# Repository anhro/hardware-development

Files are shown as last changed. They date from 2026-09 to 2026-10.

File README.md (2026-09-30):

# Hardware Development: від схеми до прототипу



Навчальний репозиторій курсу: домашні завдання та наскрізний проєкт —
**контролер BLDC-двигуна** на STM32F405 (трифазний інвертор 12 В / 14 А).

**Поточний стан:** виконано ДЗ 1–8. Схема: силовий інвертор (AOD4184A),
драйвер затворів DRV8305, MCU STM32F405 з конфігурацією CubeMX; прошивка
збирається в CI. Друкована плата — не розпочата.
Відкриті інженерні питання — у [`design-notes.md`](motor-drive-controller/docs/design-notes.md).

| Що | Де |
|----|----|
| Звіти домашніх завдань і посилання на здачу (Release / PR) | [`assignments/`](assignments/) |
| Проєкт курсу: схема, прошивка, документація | [`motor-drive-controller/`](motor-drive-controller/) |
| Власні макетні проєкти (breadboard): схема, фото, прошивка | [`prototypes/`](prototypes/) |
| Як переглянути роботу (для викладача) | [`docs/reviewer-guide.md`](docs/reviewer-guide.md) |
| Процес роботи, інструменти, правила репозиторію | [`docs/workflow.md`](docs/workflow.md) |
| Релізи (звіт `.docx`, схема PDF, BOM для кожного ДЗ) | [Releases](https://github.com/anhro/hardware-development/releases) |

## Швидкий старт

```bash
git clone https://github.com/anhro/hardware-development.git
cd hardware-development
make setup          # git-налаштування + завантаження datasheets
make help           # усі команди
```

Основні команди:

| Команда | Результат |
|---|---|
| `make datasheets` | завантажує PDF за маніфестами `datasheets.txt` |
| `make hardware` | ERC, схема у PDF, BOM → `build/hardware/` |
| `make report HW=08` | звіт ДЗ 8 у `.docx` → `build/reports/` |
| `make firmware` | збірка прошивки (CMake + arm-none-eabi-gcc) |
| `make hardware PROJECT=stepper-motor` | те саме для іншого проєкту (корінь або `prototypes/`); так само `firmware` |

Потрібно: `git`, `make`, `python3`; для звітів — `pandoc` **або** Docker;
для схем — KiCad 10 **або** Docker; для прошивки — STM32CubeCLT або
`gcc-arm-none-eabi` + `cmake` + `ninja`. Для VS Code є рекомендовані розширення
(`.vscode/extensions.json`).

## Здача домашнього завдання

```
гілка hwNN → коміти → push → Pull Request (посилання на сайт курсу + .docx)
          → правки в тій самій гілці → Merge (merge commit) → тег hwNN → Release
```

CI перевіряє кожен PR (ERC, схема PDF, BOM, звіти `.docx`, прошивка) і за тегом
`hwNN` створює Release. Для кожного PR у папці завдання ведуться опис
(`pull-request.md`) і перевірка за чеклістом (`checklist.md`); шаблон чекліста —
[`.github/pull_request_template.md`](.github/pull_request_template.md).
Детально — [`docs/workflow.md`](docs/workflow.md).

## Структура

```
.
├── assignments/                 # ДЗ: README.md (звіт) + images/ + симуляції *.asc
│   └── homework_NN/             #   з ДЗ 8 — також pull-request.md, checklist.md
├── motor-drive-controller/
│   ├── docs/                    # архітектура, інженерні рішення
│   ├── hardware/
│   │   ├── kicad/               # проєкт KiCad: листи MCU, Gate Driver, Inverter
│   │   │   └── lib/parts/<PART>/ # символ, <PART>.pretty/ (footprint), 3D
│   │   ├── simulations/ltspice/ # симуляції вузлів
│   │   └── datasheets/          # лише маніфест datasheets.txt, PDF — локально
│   └── firmware/                # STM32CubeMX (.ioc) + CMake-проєкт + HAL
├── prototypes/                  # власні макетні проєкти, структура як у проєкті курсу
│   └── <name>/                  #   README.md (фото макета, таблиця з'єднань),
│                                #   docs/images/, hardware/{kicad,datasheets}/, firmware/
├── docs/                        # процеси та інструкції
├── tools/                       # скрипти автоматизації
├── .github/
│   ├── workflows/ci.yml         # CI: схема/BOM/прошивка всіх проєктів, звіти, релізи
│   └── pull_request_template.md # чекліст PR
└── Makefile
```

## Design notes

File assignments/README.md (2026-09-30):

# Домашні завдання

| № | Тема | Звіт | Файли проєкту | Здача |
|---|---|---|---|---|
| 1 | Робоче середовище, пошук компонента | [README](homework_01/README.md) | — | [hw01](https://github.com/anhro/hardware-development/releases/tag/hw01) |
| 2 | Основні поняття в електроніці | [README](homework_02/README.md) | LTspice: [`homework_02/`](homework_02/) | [hw02](https://github.com/anhro/hardware-development/releases/tag/hw02) |
| 3 | Компонентна база: пасивні та активні компоненти | [README](homework_03/README.md) | — | [hw03](https://github.com/anhro/hardware-development/releases/tag/hw03) |
| 4 | Аналогова схемотехніка. Симуляції схем | [README](homework_04/README.md) | LTspice: [`homework_04/`](homework_04/) | [hw04](https://github.com/anhro/hardware-development/releases/tag/hw04) |
| 5 | Цифрова схемотехніка. Симуляції схем | [README](homework_05/README.md) | LTspice, розрахунок ЦАП (`.xlsx`) | [hw05](https://github.com/anhro/hardware-development/releases/tag/hw05) |
| 6 | Інтерфейс KiCad та створення проєкту | [README](homework_06/README.md) | [`inverter.kicad_sch`](../motor-drive-controller/hardware/kicad/inverter.kicad_sch) | [hw06](https://github.com/anhro/hardware-development/releases/tag/hw06) |
| 7 | Архітектура MCU та системи живлення | [README](homework_07/README.md) | [`mcu.kicad_sch`](../motor-drive-controller/hardware/kicad/mcu.kicad_sch), [`.ioc`](../motor-drive-controller/firmware/motor-drive-controller.ioc) | [hw07](https://github.com/anhro/hardware-development/releases/tag/hw07) |
| 8 | Електричні двигуни. Принципи роботи і керування | [README](homework_08/README.md) | [`gate-driver.kicad_sch`](../motor-drive-controller/hardware/kicad/gate-driver.kicad_sch), [`mcu.kicad_sch`](../motor-drive-controller/hardware/kicad/mcu.kicad_sch), [`.ioc`](../motor-drive-controller/firmware/motor-drive-controller.ioc) | [PR #1](https://github.com/anhro/hardware-development/pull/1) |

**Здача:** Release `hwNN` — зафіксований стан на момент здачі з готовими файлами
(звіт `.docx`, схема PDF, BOM); PR — завдання на перевірці. Після прийняття PR
зливається в `master` і позначається тегом `hwNN` (див. [`docs/workflow.md`](../docs/workflow.md)).

ДЗ 1–7 перенесені з `.docx` (pandoc) без змін змісту. Починаючи з ДЗ 6 схеми
живуть у проєкті [`motor-drive-controller`](../motor-drive-controller/).
Починаючи з ДЗ 8 кожне завдання здається через Pull Request; у папці завдання,
крім звіту, лежать опис PR (`pull-request.md`) і перевірка за чеклістом
(`checklist.md`).

Новий звіт: `cp -r assignments/TEMPLATE assignments/homework_NN`,
`.docx` для сайту: `make report HW=NN`.

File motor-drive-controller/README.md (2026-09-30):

# motor-drive-controller

Контролер трифазного BLDC-двигуна: 12 В, до 14 А (168 Вт).

| Вузол | Стан | Файли |
|---|---|---|
| Силовий інвертор: 3 напівмости AOD4184A, шунти WSR5 7.5 мОм | схема (ДЗ 6) | [`hardware/kicad/inverter.kicad_sch`](hardware/kicad/inverter.kicad_sch) |
| MCU STM32F405RGT6: живлення, HSE 8 МГц, JTAG/SWD, VBAT, роз'єм датчиків Холла | схема (ДЗ 7, 8) | [`hardware/kicad/mcu.kicad_sch`](hardware/kicad/mcu.kicad_sch) |
| Драйвер затворів DRV83053PHP (DRV8305): накачка заряду, VREG 3.3 В, nFAULT/PWRGD | схема (ДЗ 8) | [`hardware/kicad/gate-driver.kicad_sch`](hardware/kicad/gate-driver.kicad_sch) |
| Конфігурація MCU: SYSCLK 168 МГц (HSE → PLL), TIM1 CH1–3/CH1N–3N → INHA…INLC, входи DRV_nFAULT/DRV_PWRGD, HALL1–3, ADC1 IN10 (NTC) | CubeMX (ДЗ 7, 8) | [`firmware/motor-drive-controller.ioc`](firmware/motor-drive-controller.ioc) |
| Прошивка: ініціалізація периферії, збірка CMake | збирається в CI | [`firmware/`](firmware/) |
| Друкована плата | не розпочато | [`hardware/kicad/motor-drive-controller.kicad_pcb`](hardware/kicad/motor-drive-controller.kicad_pcb) |

## Сигнали MCU

| Сигнал | Пін | Функція | Куди |
|---|-----|---|---|
| INHA / INLA | PA8 / PA7 | TIM1_CH1 / CH1N | DRV8305 |
| INHB / INLB | PA9 / PB0 | TIM1_CH2 / CH2N | DRV8305 |
| INHC / INLC | PA10 / PB1 | TIM1_CH3 / CH3N | DRV8305 |
| DRV_nFAULT | PC4 | вхід (open-drain, 10 кОм до 3.3 В) | DRV8305 |
| DRV_PWRGD | PC5 | вхід (open-drain, 10 кОм до 3.3 В) | DRV8305 |
| HALL1–HALL3 | PC6–PC8 | вхід, FT (5 V tolerant) | роз'єм J4 |
| TEMP_SENSE | PC0 | ADC1_IN10 | NTC на інверторі |

## Готовність до розведення плати

Схема ще не готова до PCB: 123 порушення ERC, не з'єднані мітки між листами,
не підключені WAKE/EN_GATE/SPI драйвера, footprint'и пасивних компонентів не
призначені. Повний перелік — у [`docs/design-notes.md`](docs/design-notes.md#відкриті-питання).

## Документація

- Архітектура: [`docs/architecture.md`](docs/architecture.md)
- Інженерні рішення та відкриті питання: [`docs/design-notes.md`](docs/design-notes.md)
- Прошивка: [`firmware/README.md`](firmware/README.md)

```bash
make hardware    # ERC + PDF схеми + BOM -> build/hardware/
make firmware    # збірка прошивки -> firmware/build/Debug/
```

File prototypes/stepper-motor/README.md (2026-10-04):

# stepper-motor

Макетний проєкт (breadboard): керування кроковим двигуном.

<!-- TODO: мета, двигун (тип, напруга, струм фази, кроків/оберт), драйвер, MCU -->
Кроковий двигун. Тип невідомий. Розмір 40 x 40 x 32 мм. Опір кожної з двох обмоток 24 Ом.
Підозрюю що при роботі з напругою 12 В він буде нормально працювати. Струм в такому випадку
буде дорівнювати I = V / R = 12 В / 24 Ом = 0.5 А - звичайний робочий струм для такого мотора.

Мета - навчитися працювати з кроковим двигуном та використовувати драйвер A4988.

| Вузол | Стан | Файли |
|---|---|---|
| Схема макета | не розпочато | [`hardware/kicad/`](hardware/kicad/) |
| Прошивка: ESP32 (Arduino), AccelStepper; кнопки вліво/вправо → 400 кроків | збирається | [`firmware/firmware.ino`](firmware/firmware.ino) |

## Макет

<!-- Фото: docs/images/breadboard.jpg (JPEG, стиснене, до ~500 КБ) -->
<!-- ![Макет](docs/images/breadboard.jpg) -->

## З'єднання

| Від | До | Сигнал | Примітка |
|-----|----|---|---|
| | | | |

## Прошивка

Скетч Arduino: [`firmware/firmware.ino`](firmware/firmware.ino). Плата, ядро ESP32 та
бібліотеки з точними версіями — у [`firmware/sketch.yaml`](firmware/sketch.yaml);
самі бібліотеки в git не зберігаються, `arduino-cli` завантажує їх під час збірки.

- **Arduino IDE 2:** File → Open → `firmware/firmware.ino`. Плата підставиться з
  `sketch.yaml`; бібліотеку AccelStepper встановити через Library Manager.
- **Командний рядок:** `make firmware PROJECT=stepper-motor` (потрібен `arduino-cli`
  у `PATH` або `ARDUINO_CLI=/шлях/до/arduino-cli`). Завантаження в плату:
  `arduino-cli upload -p /dev/ttyUSB0 --input-dir prototypes/stepper-motor/firmware/build prototypes/stepper-motor/firmware`.
- Нова бібліотека: `arduino-cli lib install <Name>`, потім додати рядок
  `- <Name> (<версія>)` у `libraries:` профілю в `sketch.yaml`.

## Команди

```bash
make hardware PROJECT=stepper-motor    # ERC + PDF схеми + BOM -> build/hardware/
make firmware PROJECT=stepper-motor    # збірка прошивки
make datasheets                        # PDF за hardware/datasheets/datasheets.txt
```

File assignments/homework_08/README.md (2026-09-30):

# Заняття 8: Електричні двигуни. Принципи роботи і керування.

## Опис завдання
Імпортувати компонент DRV8305 та створити схему його підключення відповідно до даташиту.

1\. Імпортуйте компонент **DRV8305**.

2\. Створіть схему підключення відповідно до даташиту. Даташит можна знайти
[в папці з додатковими ресурсами](https://drive.google.com/drive/folders/10yhwZ3x6XxErtohCtULcZ-SOZ1yHaNlk?usp=drive_link).

- Необхідні зовнішні конденсатори та резистори вказані в таблиці **External Components** (ст. 5).

- Припустіть, що драйвер живиться напругою **+3V3**.

- На вхід **VDRAIN** подайте напругу живлення двигуна **+12_M**.

3\. У проєкті **STM32CubeMX** визначте виходи advanced timer, налаштовані як **PWM Generation CH1..3 та CH1..3N**.
Позначте відповідні сигнали на схемі MCU та схемі DRV8305 (**INHA…INLC**).

4\. Додайте на схему сигнали **PWRGD** та **nFAULT**. У проєкті STM32CubeMX визначте їх як входи.

- Оскільки ці сигнали є **open-drain**, вони потребують підтягувальних резисторів.

- Рекомендовані номінали резисторів наведені в таблиці **Pin Functions** даташиту.

5\. Присвойте нетам локальні мітки (**labels**) для зручності роботи зі схемою.

6\. У даташиті на **STM32F7** (додаткові ресурси до заняття 7, файл **DM00037051.pdf**,
с. 48–61) визначте піни з підтримкою **FT (5 V tolerant I/O)** та підключіть до них
на схемі MCU датчики Холла **HALL1**, **HALL2**, **HALL3**.

## Рішення завдання

1\. Імпортуємо компонент **DRV8305**.

1\.1\. В пошуку на [сайті](https://www.snapeda.com/search/?q=DRV8305&search-type=parts)
я знайшов наступні компоненти Texas Instruments:

**45-V max 3-phase smart gate driver with current shunt amplifiers & SPI**:
- DRV83053PHPR
- DRV83053PHP
- DRV83055PHP
- DRV83055PHPR
- DRV8305NPHP
- DRV8305NPHPR

**Automotive 12-V battery 3-phase smart gate driver (grade 0 & grade 1)**:
- DRV83053QPHPRQ1
- DRV83055QPHPRQ1
- DRV8305NEPHPRQ1
- DRV83055QPHPQ1
- DRV8305NQPHPQ1
- DRV83053QPHPQ1
- DRV8305NEPHPQ1
- DRV8305NQPHPRQ1

**Automotive 3-Phase Motor Gate Driver Evaluation Module**:
- DRV8305-Q1EVM

**EVAL BOARD, DRV8305 DC MOTOR DRIVER**;
Application Sub Type:DC Brushless Motor;
Silicon Manufacturer:Texas Instruments;
Kit Application Type:Power Management - Motor Control;
Silicon Core Number:DRV8305;
Kit Contents:Eval Board DRV8305;
Product Range:-;
SVHC:No SVHC (27-Jun-2018);
Features:3-PH Brushless DC Motor Driver, 15A Continuous/20A Peak O/P Current,
Thermal Protection, 4.4V-45Vin:
- BOOSTXLDRV8305EVM

1\.2\. Вибір компонента:

- Крок 1: Нам потрібна мікросхема.

Все що закінчується на **EVM** нам не подходить - це компактна плата розширення.

- Крок 2: Автомобільний чи промисловий стандарт?

Все що із суфіксом -**Q1** або літерою **Q** - це автомобільний (Automotive) стандарт.
Вони сертифіковані за стандартом AEC-Q100 (Grade 0 або 1), витримують сильні вібрації
та екстремальні температури (від -40°C до +150°C) для роботи в реальних автомобілях
від 12-вольтового акумулятора. Скоріш за все вони більш дорогі і нам теж не підходять,
тому вибираємо без позначок **Q** та **Q1**. Нам потрібен звичайний промисловий стандарт.

- Крок 3: Яка напруга потрібна для живлення мікроконтролера?

Символ що вказаний на місці знака # **DRV8305#** означає живлення: **3** - драйвер має
вбудований стабілізатор на **3.3 В**, **5** - має стабілізатор на **5.0 В**, **N** -
стабілізатор вимкнено (обирається якщо на платі вже є потужне джерело живлення,
і від драйвера потрібні тільки функції керування мотором).

В нас вже є MCU що споживає 3.3 В живлення, тому нам підходить з цифрою **3**.

- Крок 4: Як плата буде збиратися на заводі (Пакування)?

Останні літери відповідають за форму випуску для виробництва. Корпус у всіх однаковий - **HTQFP-48** (**PHP**).
Але якщо без літери **R** (наприклад, **DRV83053PHP**), то це
означає що мікросхема постачається у пластикових лотках (**Trays**). Зручно для ручної
пайки або дрібних партій. З літорою **R** наприкінці (наприклад, **DRV83053PHPR**), то
постачається в рулонах / стрічці (**Tape & Reel**). Обирається для масового серійного
виробництва, де робот-розкладач автоматично бере чипи зі стрічки. Нам підходить без літери **R**.

- Крок 5: Мій вибір **DRV83053PHP**:

**Я обираю промислову версію DRV83053PHP, тому що мій пристрій не автомобільний,
мій мікроконтролер потребує живлення 3.3 В, а корпус PHP (HTQFP-48) зручний для розведення плати і ручної пайки.**

1\.2\. Скачую її символічне значення та місце для розташування:

Завантажую компонент з сайту [SnapEDA](https://www.snapeda.com/parts/DRV83053PHP/Texas%20Instruments/view-part/?ref=search&t=DRV8305&ab_test_case=b):

- Переміщую в папку parts:
`motor-drive-controller/hardware/kicad/lib/parts/DRV83053PHP/`:

```
motor-drive-controller/hardware/kicad/lib/parts/DRV83053PHP/
├── DRV83053PHP.kicad_sym
├── DRV83053PHP.step
└── DRV83053PHP.pretty/
    └── QFP50P900X900X120-49N.kicad_mod
```

В данному випадку я створюю додаткову теку DRV83053PHP.pretty - папку-бібліотеку посадкових місць
для драйвера DRV8305.

- Імпортую в KiCad → *Preferences → Manage Symbol/Footprint Libraries → Project Specific Libraries*:

2\. Створення схеми підключення відповідно до даташиту.

## Результат

1\. **Схема драйвера**.

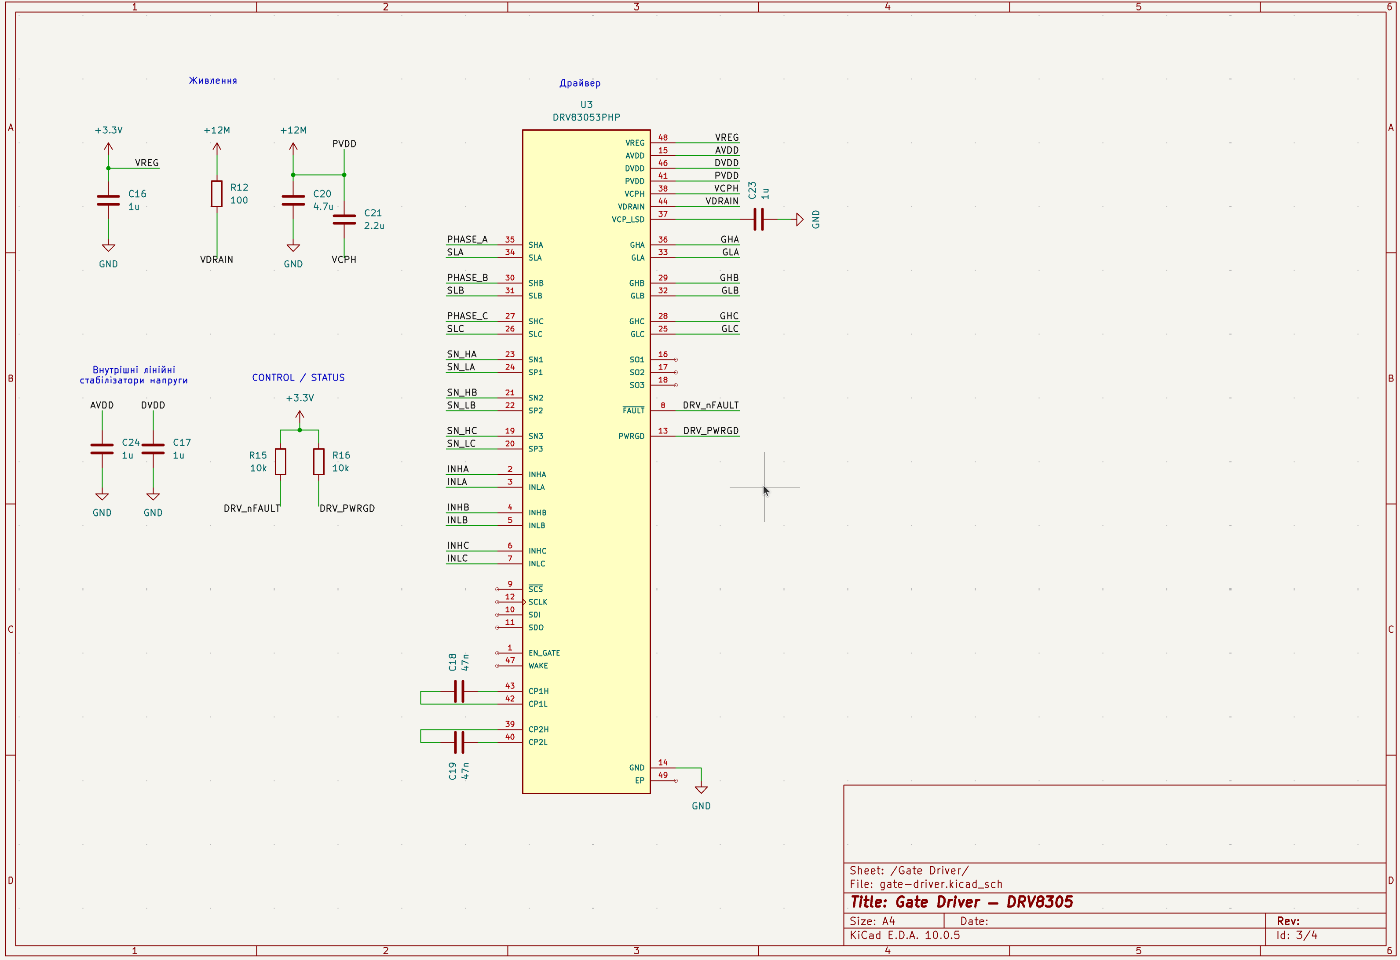
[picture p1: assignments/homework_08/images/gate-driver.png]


2\. **MCU з додатковими позначеннями виводів та роз'єм для датчиків Холла**.

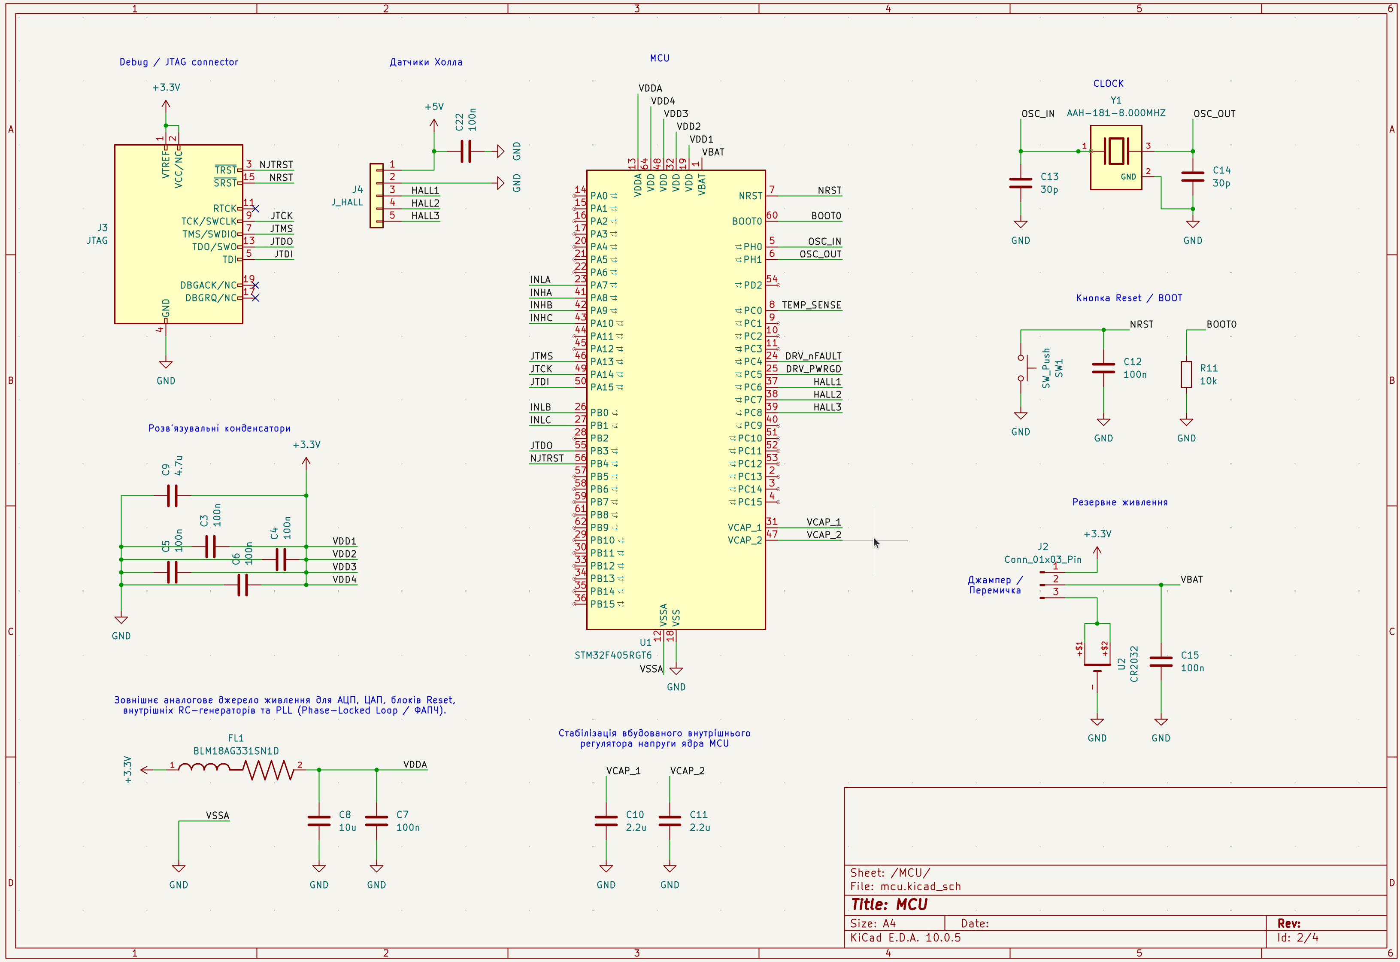
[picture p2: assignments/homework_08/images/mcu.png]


3\. **Розпіновка MCU**.

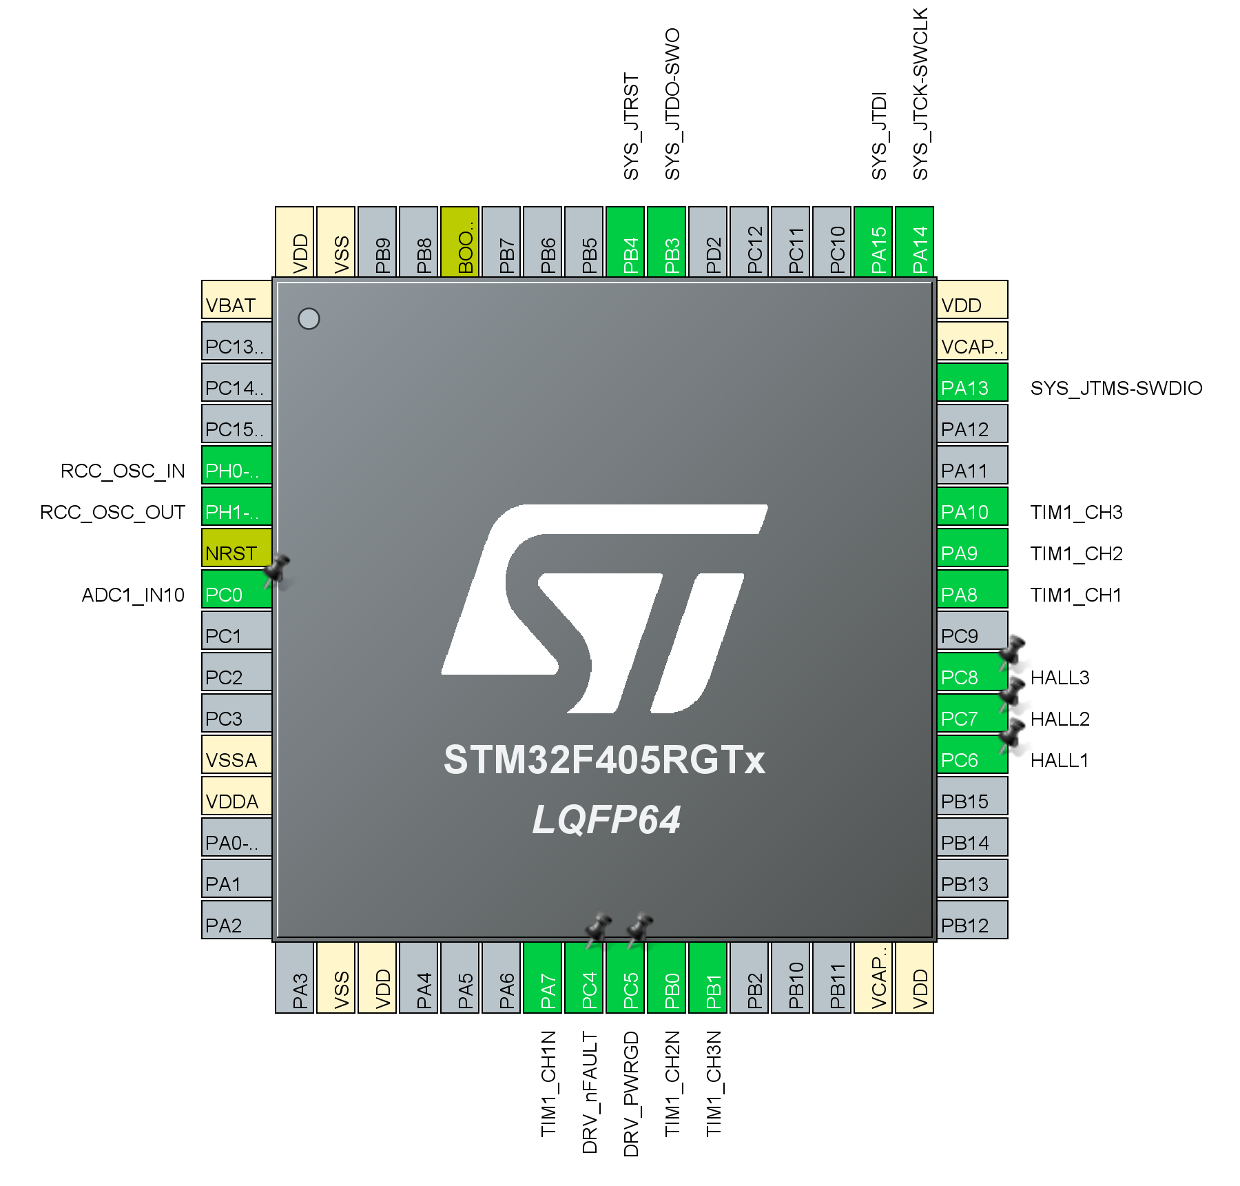
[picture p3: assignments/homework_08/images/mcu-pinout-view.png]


4\. **MCU піни з підтримкою FT**.

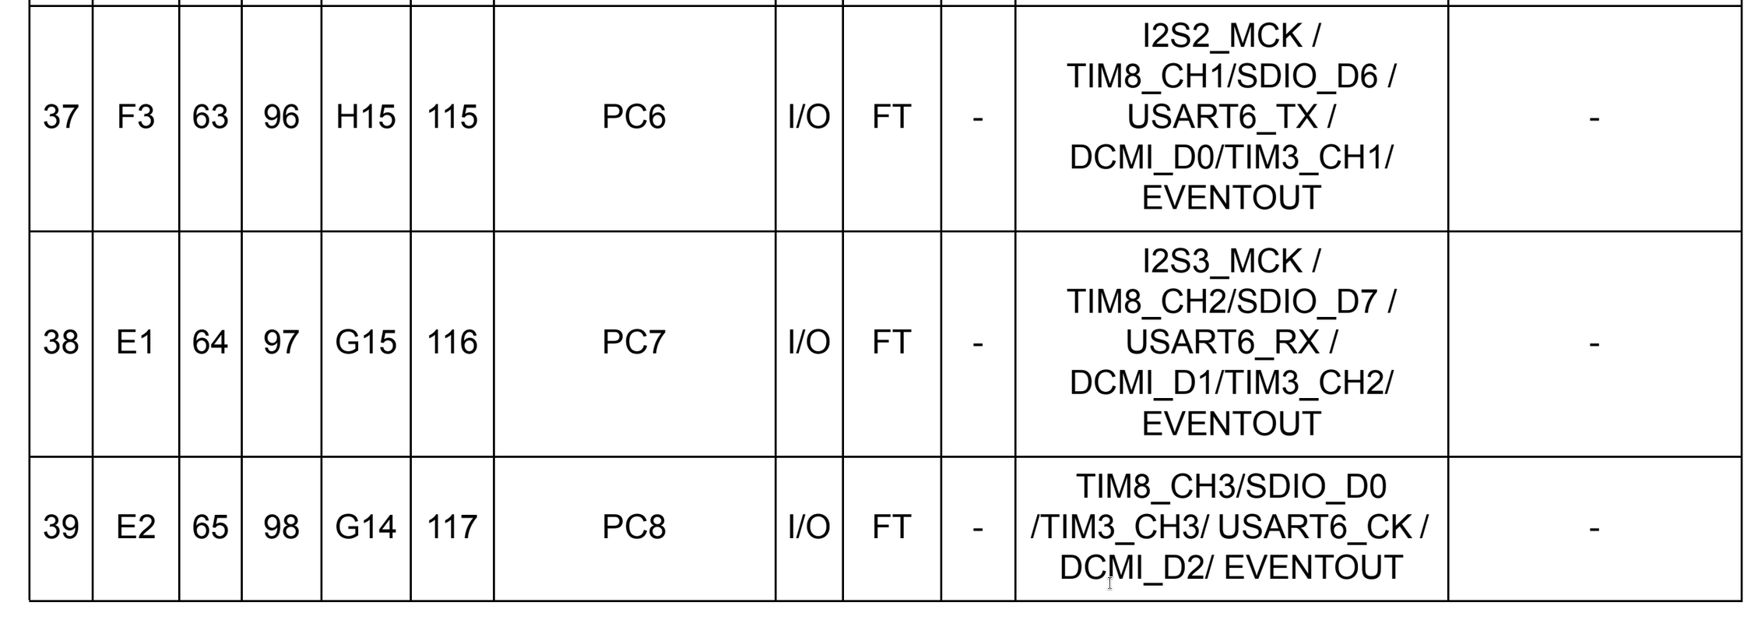
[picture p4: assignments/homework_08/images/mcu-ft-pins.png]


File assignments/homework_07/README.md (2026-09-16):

# Заняття 7: Архітектура MCU та системи живлення.

### Завдання 1

Опис завдання: в STM32CubeM сконфігурувати піни контролера STM32F405RGT (базовий варіант):

- TIM1 (CH1 CH1N)

- TIM1 (CH2 CH2N)

- TIM1 (CH3 CH3N)

- піни кварцового резонатора (RCC/HSE)

- входи програматора (SYS-JTAG)

- ADC (вхід для заміру показників термістора зі схеми 6 заняття)

Можна обрати інший мікроконтролер, якщо він має:

- за бажанням три ADC-периферії. Три окремих ADC забезпечить одночасний замір, а значить точніше керування на високих частотах обертання двигуна;

- advanced-control timer із можливістю формування комплементарного PWM для трьох каналів;

- підтримку dead time.

Вкажіть модель обраного мікроконтролера та прикріпіть скріншот Pinout view.

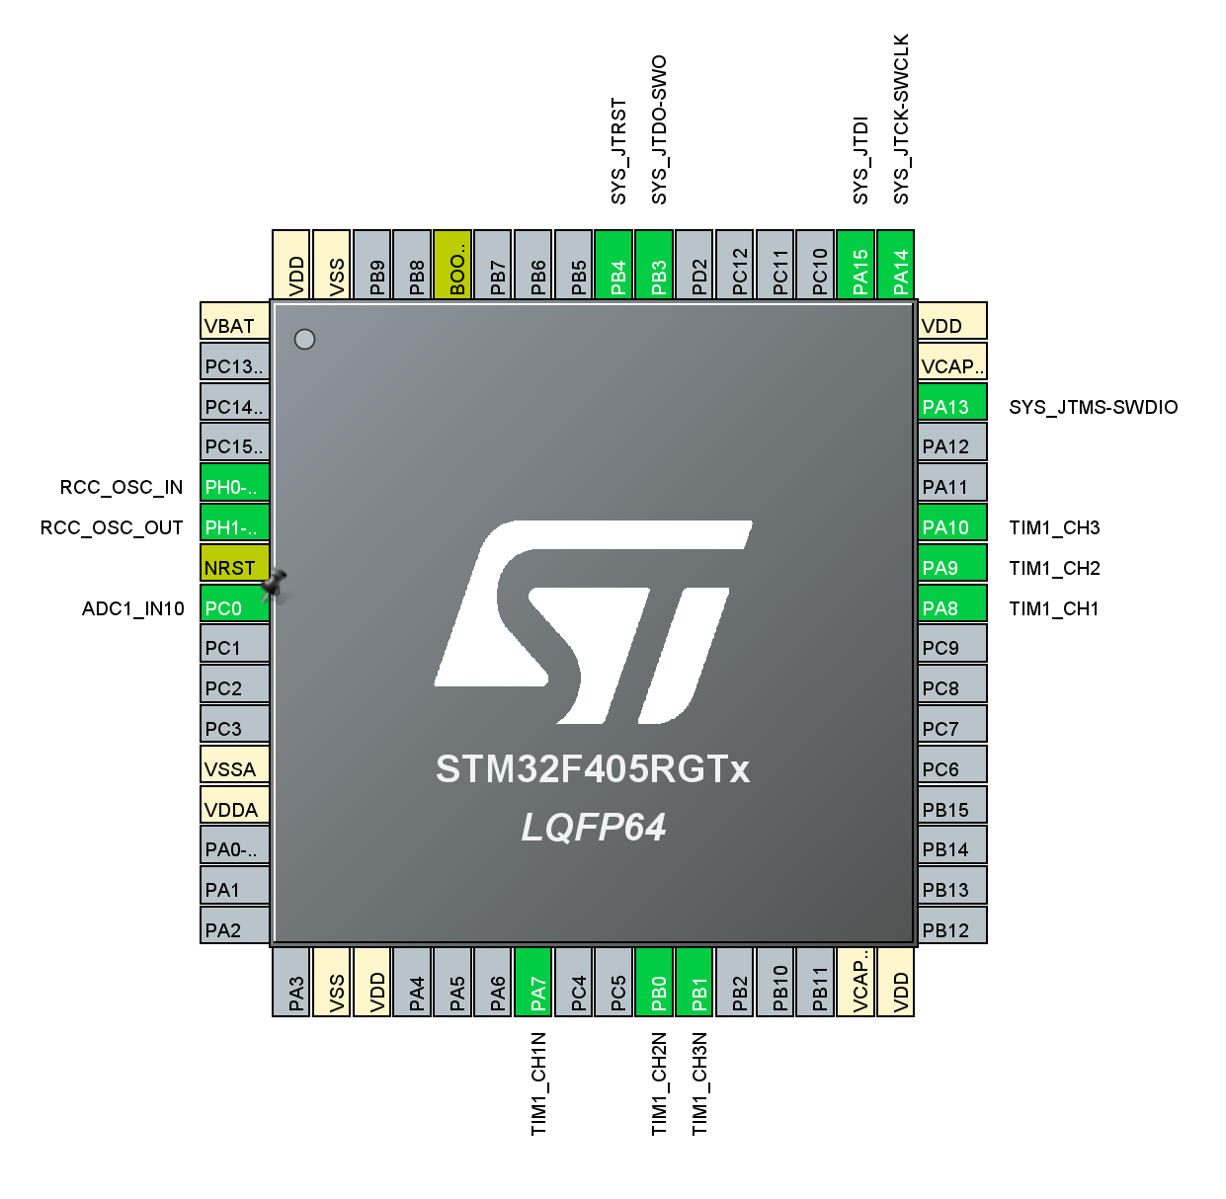
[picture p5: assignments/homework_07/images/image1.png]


### Завдання 2

Опис завдання: на окремому аркуші створіть схему мінімального підключення обраного мікроконтролера STM32Fxxx. Покажіть необхідні для роботи підключення відповідно до матеріалів слайдів 19–23: живлення та decoupling, VDDA/VSSA, NRST, BOOT, VBAT/backup domain, тактовий генератор тощо.

Вибираю кварц: AAH-181-8.000MHZ. Параметри з [datasheet](https://www.snapeda.com/parts/AAH-181-8.000MHZ/ABRACON/datasheet/) наступні:

Load capacitance (C<sub>L</sub>): 18.0 pF

C<sub>L</sub> = C1 x C2 / (C1 + C2) + Cs,

де Cs (Stray capacitance) - паразитна ємність плати Cs = 3 pF (2–5 pF)

Якщо C1 = C2 = Cext то:

C<sub>L</sub> = Cext / 2 + Cs --\> Cext / 2 = C<sub>L</sub> - Cs --\>

Cext = 2x(C<sub>L</sub> - Cs) = 2x(18.0 pF - 3 pF) = 30 pF

Додано ієрархічну структуру креслень де MCU — це поточна схема, Inverter — це схема силових ключів:

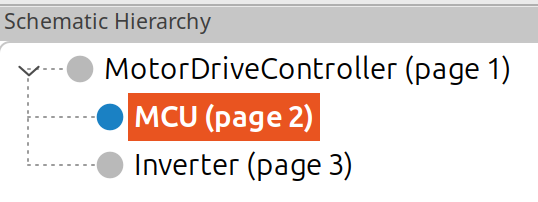
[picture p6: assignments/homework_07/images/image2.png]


Електрична схема підключення MCU STM32F405RGT6:

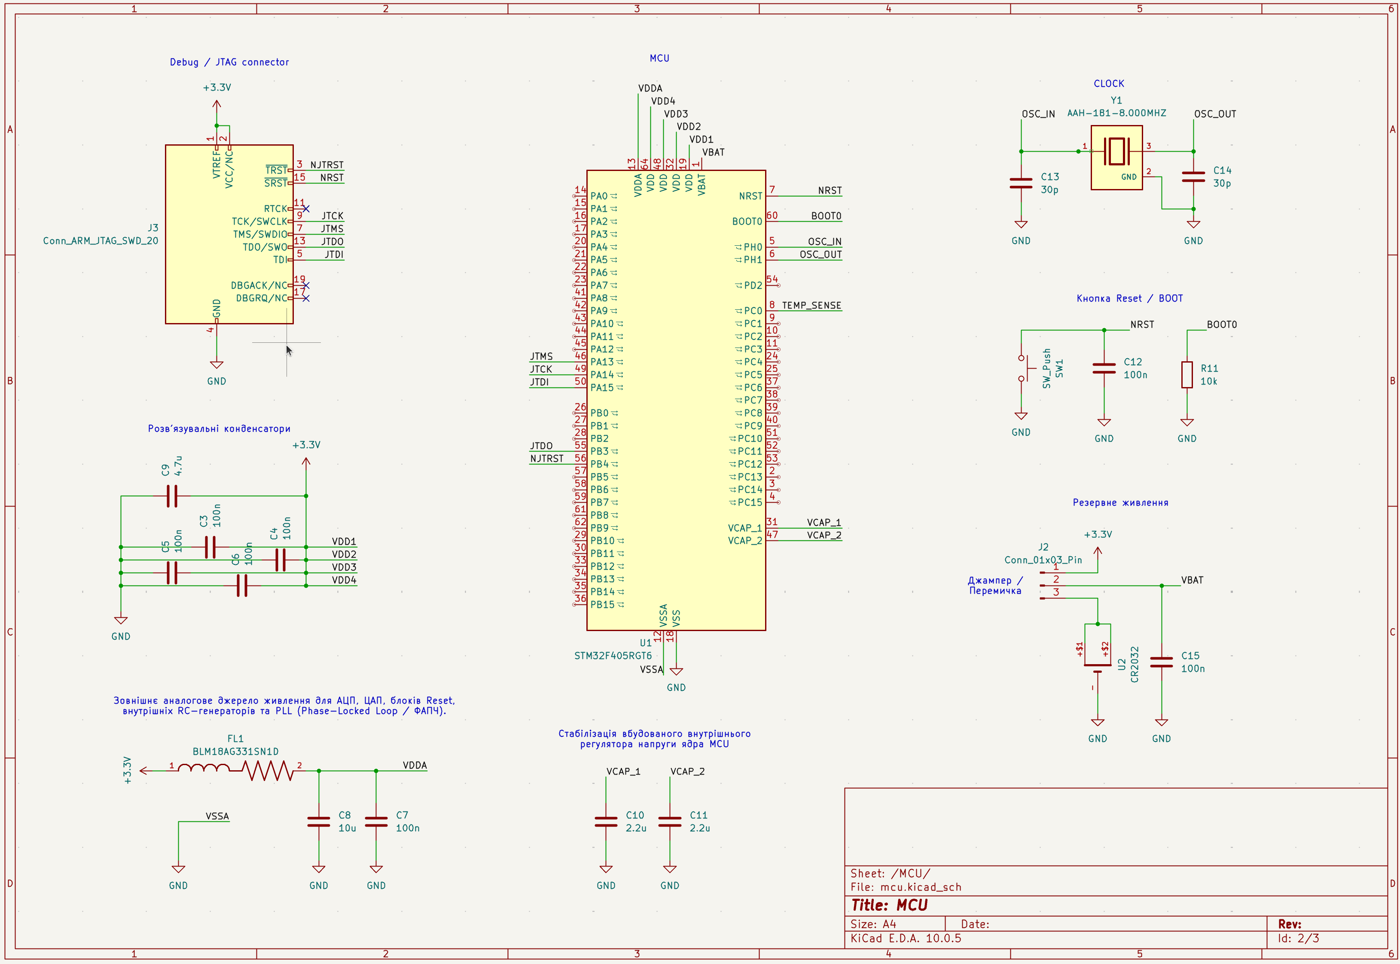
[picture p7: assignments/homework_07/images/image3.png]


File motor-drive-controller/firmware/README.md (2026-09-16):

# Прошивка

Джерело правди для пінів, тактування та периферії —
[`motor-drive-controller.ioc`](motor-drive-controller.ioc) (STM32CubeMX).
Код пишеться лише між маркерами `/* USER CODE BEGIN … */ … /* USER CODE END … */`
або в окремих файлах — інакше CubeMX перезапише його при генерації.

## Що в git

| Шлях | У git | Чому |
|---|:-----:|---|
| `motor-drive-controller.ioc` | ✅ | конфігурація |
| `Core/`, власні модулі | ✅ | код |
| `CMakeLists.txt`, `CMakePresets.json`, `cmake/`, `*.ld`, `startup_*.s` | ✅ | збірка без CubeMX (CI) |
| `Drivers/` (лише необхідні файли HAL/CMSIS) | ✅ | фіксована версія бібліотек → відтворювана збірка; змінюється тільки при оновленні FW-пакета |
| `build/`, `EWARM/`, `.mxproject` | ❌ | генерується / не використовується |

## Перехід на CMake + VS Code (одноразово)

У `.ioc` вже виставлено: *Toolchain/IDE* = **CMake**, *Code generator* =
**Copy only the necessary library files**, ім'я проєкту `motor-drive-controller`.
Раніше проєкт був згенерований для IAR EWARM і з повною копією CMSIS (57 МБ).

```bash
cd motor-drive-controller/firmware
rm -rf Drivers EWARM .mxproject     # усе це відтворюється з .ioc і FW_F4 V1.28.3
```

1. Відкрити `.ioc` у STM32CubeMX → перевірити *Project Manager* → **Generate Code**.
2. Виправити тактування й dead-time (див. [design-notes](../docs/design-notes.md#відкриті-питання)).
3. VS Code з розширенням **STM32Cube for Visual Studio Code** → *Import CMake project*.
4. Перевірити збірку: `make firmware` (з кореня репозиторію).

Для цього потрібен STM32CubeCLT (компілятор, CMake, Ninja, ST-LINK GDB server) —
розширення VS Code запропонує встановити його автоматично.

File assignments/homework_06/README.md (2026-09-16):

# Заняття 6: Інтерфейс KiCad та створення проєкту.

### Завдання 1 — підбір силових ключів та шунтів

Є приклад трифазної мостової схеми керування (три напівмости) двигуном ([у папці з додатковими ресурсами](https://drive.google.com/drive/folders/1CCpVQM1FImKKAaBql2j669Kx7Z-wt8mC?usp=sharing)). Потужність двигуна з навантаженням при напрузі 12В: 168Вт (~14А).

**Розрахувати:**

- Підібрати силові ключі для трьох напівмостів керування двигуном:

- запас по струму — мінімум 1.5–2 рази від розрахункового значення, з урахуванням температурних змін (дератинг Id при робочій температурі кристала/корпуса);

- запас по напрузі — мінімум 1.5–2 рази, комфортний запас — x3.

- Підібрати шунти для виміру струму в обмотках (коефіцієнт підсилення підсилювача — 20 В/В):

- номінал шунта розрахувати з запасом на 50% понад очікуваний піковий струм;

- 3.3В — максимальна напруга вимірювального сигналу на виході підсилювача

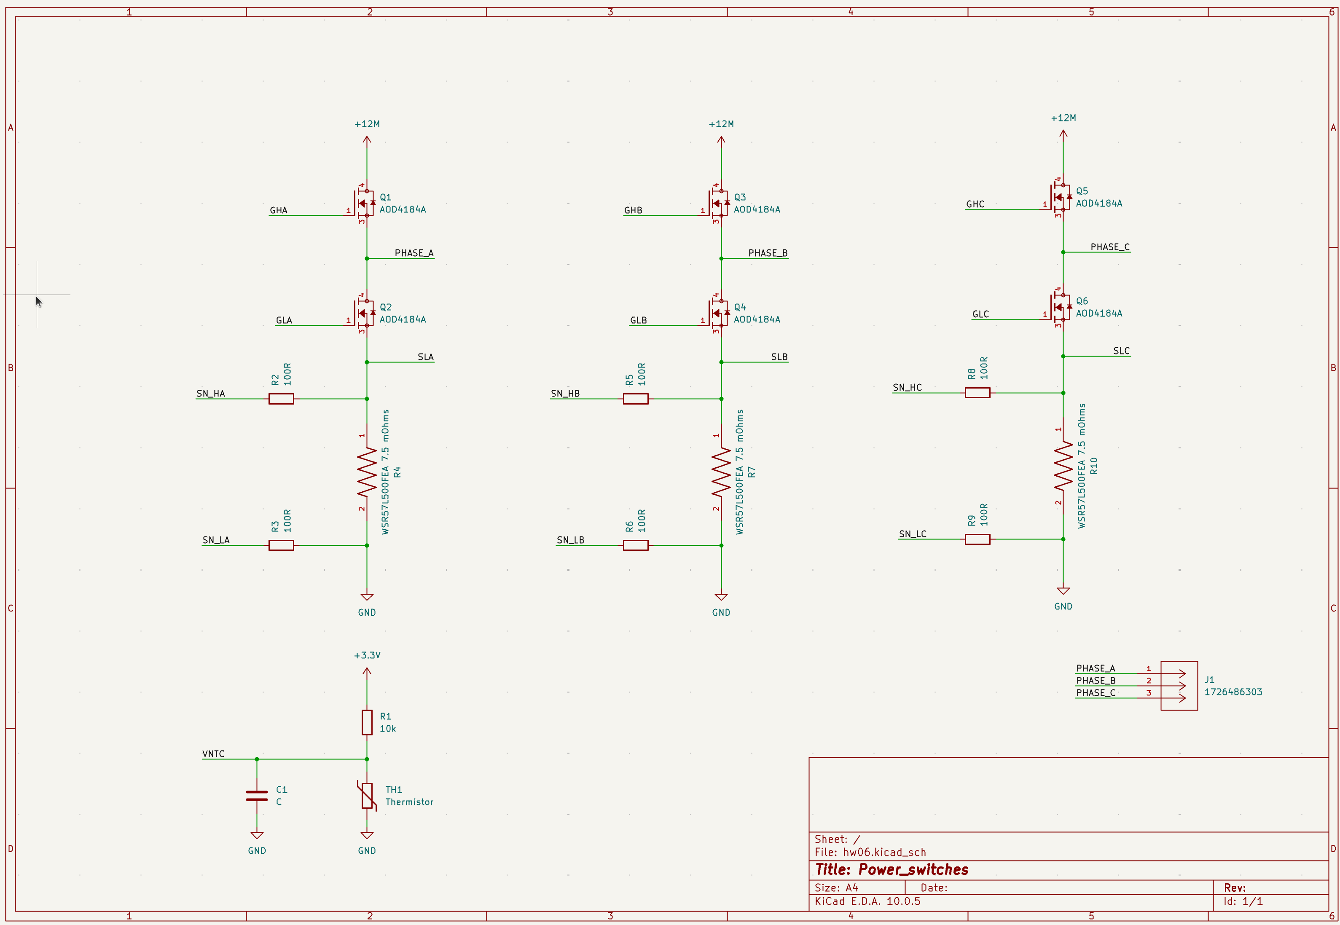
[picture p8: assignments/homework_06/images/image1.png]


**Підібрати ключі:**

Виявляється (для мене :) що одночасно струм через трифазний двигун, що керується ключами MOSFET, поступає тільки через одну пару фаз — AB, BC, CA (на відміну від трьохфазного двигуна змінного струму AC), і струм проходить максимальний для постійного джерела живлення — Imax = 168 Вт / 12 А = 14 А.

Добре. Тоді закладемо запас, що вказаний в умовах задачі - запас по струму — мінімум 1.5–2 рази від розрахункового значення.

Для запасу в 1.5 рази відповідний струм буде Imax 1.5 = 14 А \* 1.5 = 21 А.

Для запасу в 2 рази відповідний струм буде Imax 2 = 14 А \* 2 = 28 А.

Закладемо запас по напрузі - запас по напрузі — мінімум 1.5–2 рази, комфортний запас — x3.

Для запасу в 1.5 рази Umax = 12 В \* 1.5 = 18 В.

Для запасу в 2 рази Umax = 12 В \* 2 = 24 В.

Для комфортного запасу в 3 рази Umax = 12 В \* 3 = 36 В.

В нашому випадку для підбору ключів нам потрібен ключ у якого максимальні значення більші або дорівнюють розрахованим величинам:

Imax = {21, 28} А, Umax = {18, 24, 36} В.

N-Channel [MOSFETs](https://octopart.com/search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)

| MOSFET | V<sub>DS</sub> | I<sub>D</sub> A |  | R<sub>DS(on)</sub> | Q<sub>g</sub> | V<sub>GS</sub> | Корпус | Примітка |
|----|:--:|:--:|:--:|:--:|:--:|:--:|:--:|:--:|
|  |  | 25 °C | 100 °C |  |  |  |  |  |
| [IRLR3714](https://octopart.com/datasheet/infineon/IRLR3714) | 20 | 36 | 31 (70 °C) | 0.02 | 6.5 | 10 V | D-Pak / I-Pak |  |
| [IRFR3704](https://octopart.com/datasheet/infineon/IRFR3704) | 20 | 75 | 63 (70 °C) | 0.0095 | 19 | 10 V | D-Pak / I-Pak |  |
| [IPD060N03LGATMA1](https://octopart.com/datasheet/infineon/IPD060N03LGATMA1) | 30 | 50 | 50 | 0.006 | 10.8 | 10 V | PG-TO251-3 |  |
| [FQP30N06L](https://octopart.com/datasheet/onsemi/FQP30N06L) | 60 | 32 | 22.6 | 0.035 | 15 | 10 V | TO-220 |  |
| [IRFZ34NPBF](https://octopart.com/datasheet/infineon/IRFZ34NPBF) | 55 | 29 | 20 | 0.040 | 34 | 10 V | TO-220AB |  |
| [STD30NF04LT](https://octopart.com/datasheet/stmicroelectronics/STD30NF04LT) | 40 | 30 | 21 | 0.03 | 17 | 10 V | DPAK |  |
| [IRL3705NPBF](https://octopart.com/datasheet/infineon/IRL3705NPBF) | 55 | 89 | 63 | 0.010 | 98 | 10 V | TO-220AB |  |
| [IRLR2703](https://octopart.com/datasheet/international-rectifier/IRLR2703) | 30 | 23 | 16 | 0.045 | 15 | 10 V | D-Pak / I-Pak |  |
| [IPD050N03L](https://octopart.com/datasheet/infineon/IPD050N03LGATMA1) | 30 | 50 | 50 | 0.005 | 15 | 10 V | PG-TO252-3-11 |  |
| [SUD50N03-06AP-E3](https://octopart.com/datasheet/vishay/SUD50N03-06AP-E3) | 30 | 30 | 25 (70 °C) | 0.0046 | 30 | 10 V | TO-252 |  |
| [AOD4184A](https://octopart.com/datasheet/alpha-omega-semiconductor/AOD4184A) | 40 | 50 | 40 | 0.0058 | 27 | 10 V | TO-252 |  |
| [IRFR3303PBF](https://octopart.com/datasheet/infineon/IRFR3303PBF) | 30 | 33 | 21 | 0.031 | 29 | 10 V | D-Pak / I-Pak |  |
| [IPD06N03LAG](https://octopart.com/datasheet/infineon/IPD06N03LAG) | 25 | 50 | 50 | 0.0057 | 17 | 10 V | P-TO252-3-11 |  |
| [STP60NF06](https://octopart.com/datasheet/stmicroelectronics/STP60NF06) | 60 | 60 | 42 | 0.014 | 54 | 10 V | TO-220 |  |
| [IRLZ44NPBF](https://octopart.com/datasheet/infineon/IRLZ44NPBF) | 55 | 47 | 33 | 0.022 | RV | 10 V | TO-220AB |  |

Таблиця кандидатів у відбір кращих силових ключів

<table>
<colgroup>
<col style="width: 15%" />
<col style="width: 28%" />
<col style="width: 26%" />
<col style="width: 28%" />
</colgroup>
<thead>
<tr>
<th style="text-align: center;">I<sub>D</sub> \ V<sub>DS</sub></th>
<th style="text-align: center;">≥18 V</th>
<th style="text-align: center;">≥24 V</th>
<th style="text-align: center;">≥36 V</th>
</tr>
</thead>
<tbody>
<tr>
<td style="text-align: center;"><strong>≥21 A</strong></td>
<td style="text-align: center;">---</td>
<td>1. IRLR2703 (30V, 23A)</td>
<td style="text-align: center;">---</td>
</tr>
<tr>
<td style="text-align: center;"><strong>≥28 A</strong></td>
<td style="text-align: center;"><p>1. IRLR3714 (20V, 36A)</p>
<p>2. IRFR3704 (20V, 75A)</p></td>
<td><p>1. IPD060N03L (30V, 50A)</p>
<p>2. IPD050N03L (30V, 50A)</p>
<p>3. SUD50N03 (30V, 30A)</p>
<p>4. IRFR3303PBF (30V, 33A)</p>
<p>5. IPD06N03LAG (25V, 50A)</p></td>
<td style="text-align: center;"><p>1. FQP30N06L (60V, 32A)</p>
<p>2. IRFZ34NPBF (55V, 29A)</p>
<p>3. STD30NF04LT (40V, 30A)</p>
<p>4. IRL3705NPBF (55V, 89A)</p>
<p>5. AOD4184A (40V, 50A)</p>
<p>6. STP60NF06 (60V, 60A)</p>
<p>7. IRLZ44NPBF (55V, 47A)</p></td>
</tr>
</tbody>
</table>

Вибираємо по максимальній напрузі та струму (≥28 A та ≥36 V) — права нижня комірка:

Найкращим вибором є AOD4184A (R<sub>DS</sub>(on) = 0.0058 Ом) або IRL3705NPBF (має великий запас за струмом 89A та низький опір 0.010 Ом).

**Мій вибір:**

З двох кандидатів вибираю AOD4184A. Безперервний струм стоку при 25 °C I<sub>D</sub> = 50A. Крім того він гарно тримається при нагріванні до 100 °C (I<sub>D</sub> = 40A).

Це також ключ з низьким опором відкритого каналу R<sub>DS</sub>(on) = 0.0058 Ом. Чим менше опору, тим менше втрат потужності на нагрівання.

Формула для розрахунку втрати потужності: P = I<sup>2</sup> x R<sub>DS</sub>(on).

Подивимося на різницю в нагріванні при струмі двигуна, наприклад, 25 А.

Наприклад,

- Для IRL3705NPBF: R<sub>DS</sub>(on) = 0.010 Ом. --\> P = 25<sup>2</sup> x 0.010 = 6.25 Вт

- Для AOD4184A: R<sub>DS</sub>(on) = 0.0058 Ом. --\> P = 25<sup>2</sup> x 0.0058 = 3.625 Вт

Тобто при одному і тому ж струмі на ключі AOD4184A виділяється майже в 2 рази менше ніж на IRL3705NPBF.

Крім того це транзистор в SMD-корпусі (TO-252).

Згідно datasheet, у нього вказаний параметр Power Dissipation A (це використання в реальних умовах без радіатора — на платі достатньо наявності квадратної площадки в 1 квадратний дюйм 25.4 x 25.4 мм = 6.45 см<sup>2</sup>):

- При T<sub>A</sub> = 25 °C --\> P<sub>DSM</sub> = 2.3 Вт.

- При T<sub>A</sub> = 100 °C --\> P<sub>DSM</sub> = 1.5 Вт.

При струмі в 14 А розраховуємо потужність розсіювання, Вт:

- P = 14<sup>2</sup> x 0.0058 = 1.1368 Вт ≈ 1.15 Вт.

**Висновок:**

Ключ AOD4184A у SMD корпусі при наявності на платі мідної площадки площою в 6.45 см<sup>2</sup>, навіть при нагріві навколишнього середовища до температури 100 °C цей ключ зможе розсіювати потужність в 1.15 Вт (1.15 Вт \< 1.5 Вт) без будь-яких зовнішніх алюмінієвих радіаторів з запасом майже в 1.5 рази. Тоді як при кімнатній температурі цей показник виявляється ще більше комфортним (1.15 Вт \< 2.3 Вт) — в 2 рази менший.

**Порахуємо шунти:**

Нам відомі наступні первинні умови:

- Коефіцієнт підсилення підсилювача A<sub>CL</sub> = 20 В/В;

- Номінал шунта розрахувати з запасом на 50% (SF = 1.5) понад очікуваний піковий струм;

- Максимальна напруга вимірювального сигналу на виході підсилювача:

  Uout max = 3.3 В;

Підемо з кінця — найбільше наше обмеження — це максимальна напруга на виході підсилювача, яку нам не можна перевищувати.

Розраховуємо максимальну напругу на вході підсилювача:

Uin max = Uout max / A<sub>CL</sub> = 3.3 В / 20 = 0.165 В.

І відповідно максимальна напруга на шунті повинна дорівнювати максимальній вхідній напрузі:

Ush max = Uin max = 0.165 В

Розраховуємо з запасом максимальний піковий струм що проходить через шунт Ish max = Imax \* SF (Safety Factor) = 14 А \* 1.5 = 21 А

В нас є максимальна напруга на шунті, є максимальний струм. Тепер розрахуємо максимальний опір шунта:

Rsh = Ush max / Ish max = 0.165 В / 21 А = 0.007857143 Ом ≈ 7.5 мОм (шукаємо по таблиці найближчий менший опір, тому що більший збільшить нашу максимальну напругу на вході підсилювача).

Так як всі ці три напівмости для керування двигуном однакові, то відповідь буде наступною:

**Розрахований опір шунта** Rsh = 7.5 мОм.

Перевірка:

Шунт Rsh = 7.5 мОм, піковий струм на ньому Ish = 14 А \* 1.5 = 21 А. Тоді максимальна напруга на шунті Ush = Rsh \* Ish = 7.5 мОм \* 21 А = 0.1575 В.

На виході підсилювача ми отримаємо Uout = Ush \* A<sub>CL</sub> = 0.1575 В \* 20 = 3.15 В.

Це менше ніж максимальна допустима напруга на виході з підсилювача:

3.15 В \< 3.3 В

При цьому чистий запас АЦП = (3.3 В - 3.15 В)/ 3.3 В \* 100% ≈ 4.5%, що впевнено захищає від насичення через наявність безпечного проміжка по напрузі:

3.3 В - 3.15 В = 0.15 В.

**Підбір footprint для шунта:**

Розрахуємо потужність нашого шунта: Psh = Ush max \* Ish max = 0.165 В \* 21 А = 3.465 Вт. Потрібно вибирати найближче більше стандартне значення потіжності = 5 Вт

Вибираю для шунта наступний SMD резистор: [WSR57L500FEA](https://www.vishay.com/docs/31059/wsrhighpower.pdf) з такими параметрами:

- Resistance: 7.5 mOhms

- Power Rating: 5 W

- Manufacturer: Vishay

Для нього вказано наступний footprint (який чомусь відсутній в KiCad):

- GLOBAL MODEL: WSR5

- SIZE: 4527

Корпус 4527 J-Lead має дюймові розміри приблизно 0.45 x 0.27 дюйма (11.56 × 6.98 мм). Це 2 контактних площадки розміром 3.94 мм x 5.84 мм, між якими відстань 5.12 мм.

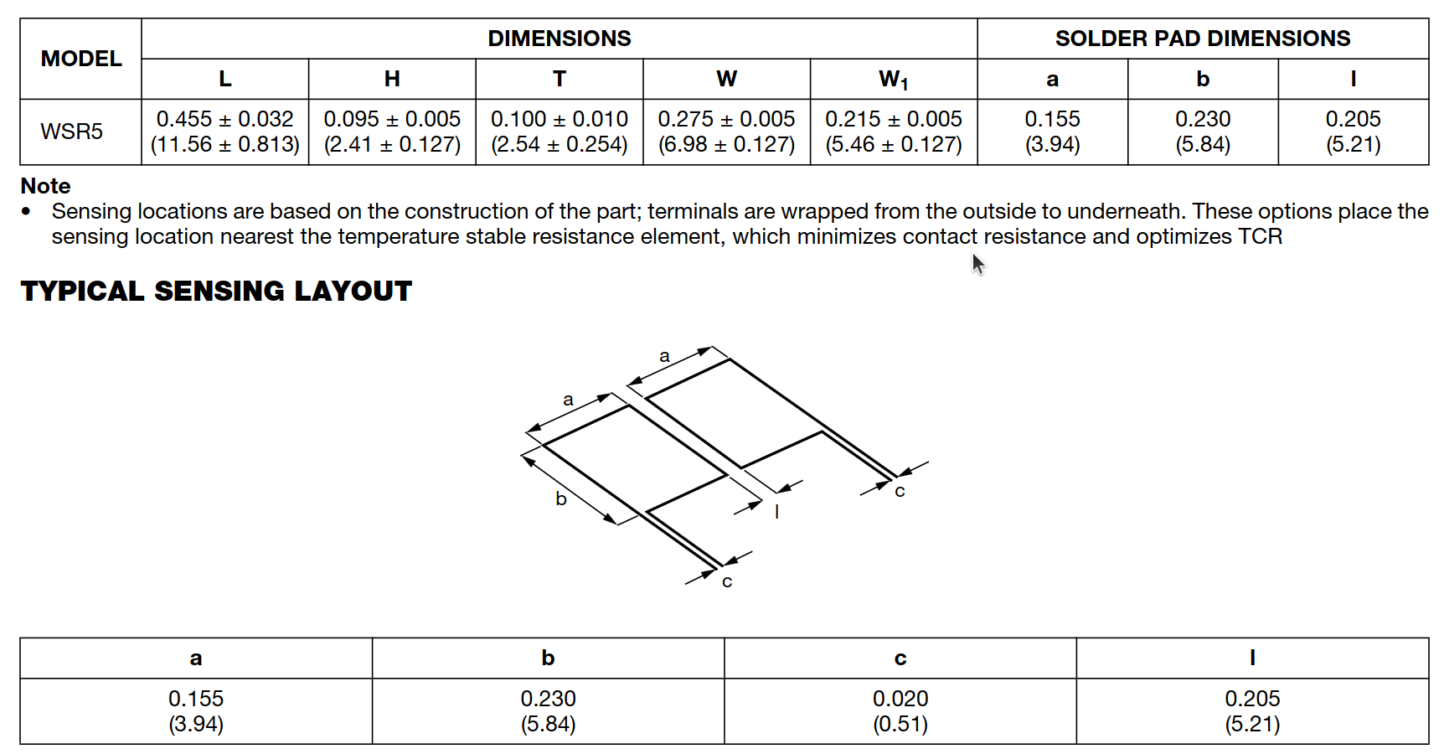
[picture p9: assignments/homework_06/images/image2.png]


Знайшов корпус по назві WSR57L500FEA на [сайті https://www.snapeda.com](https://www.snapeda.com/parts/WSR57L500FEA/Vishay/view-part/?ref=search&t=WSR57L500FEA&ab_test_case=b).

Імпортував в свою бібліотеку KiCad:

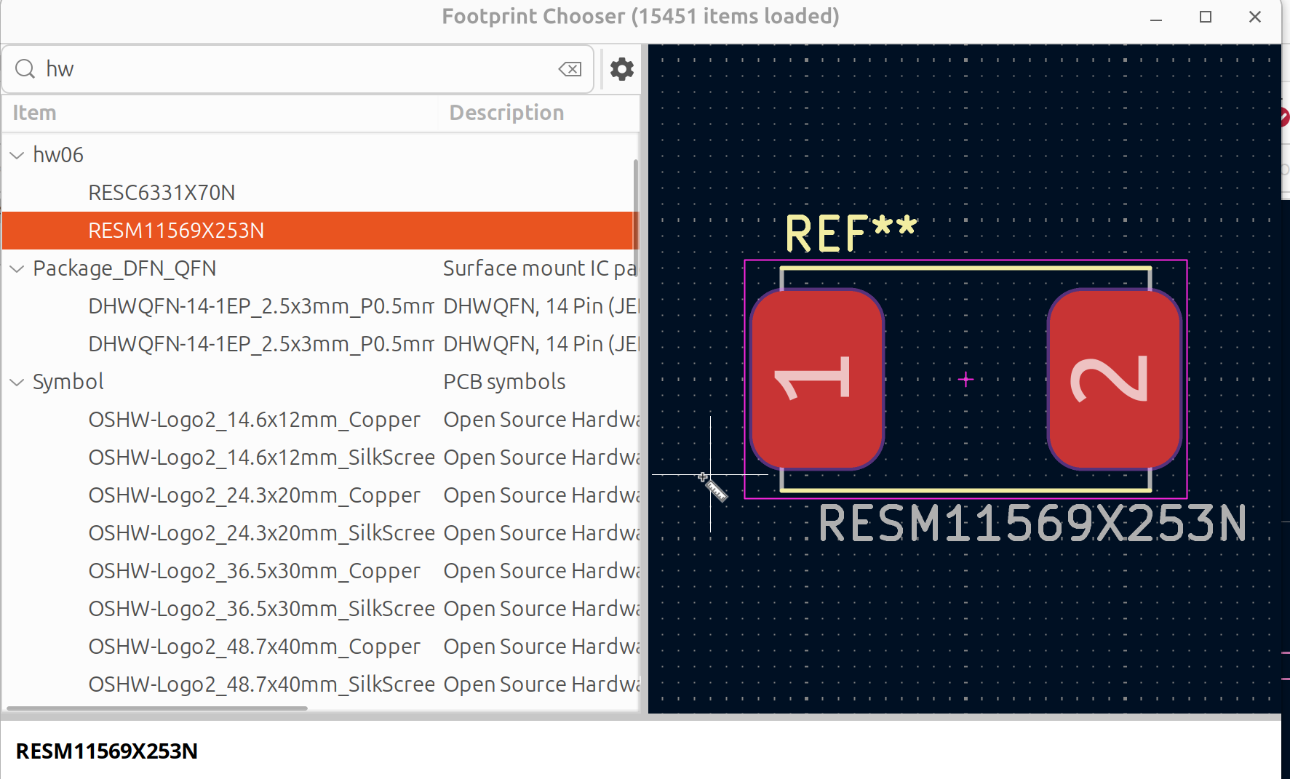
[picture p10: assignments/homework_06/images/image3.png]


На платі в KiCad:

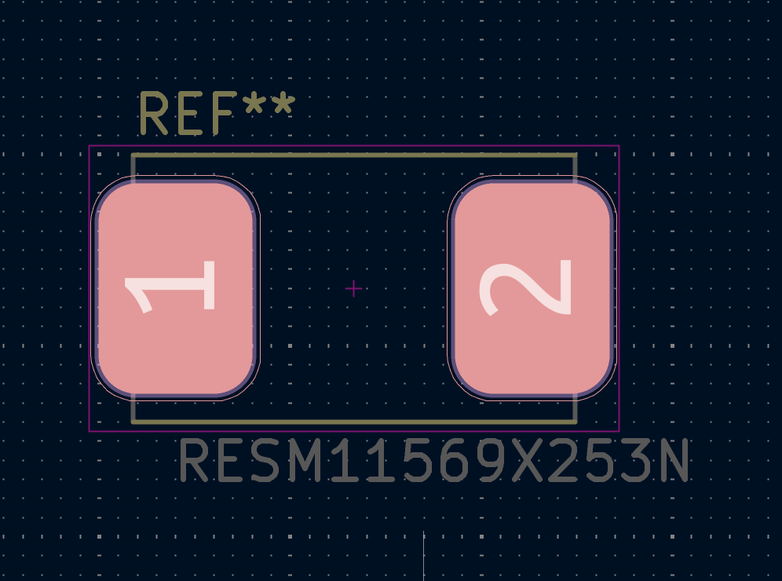
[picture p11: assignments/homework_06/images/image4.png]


### Завдання 2 — схема силової частини

Створіть схему силової частини.

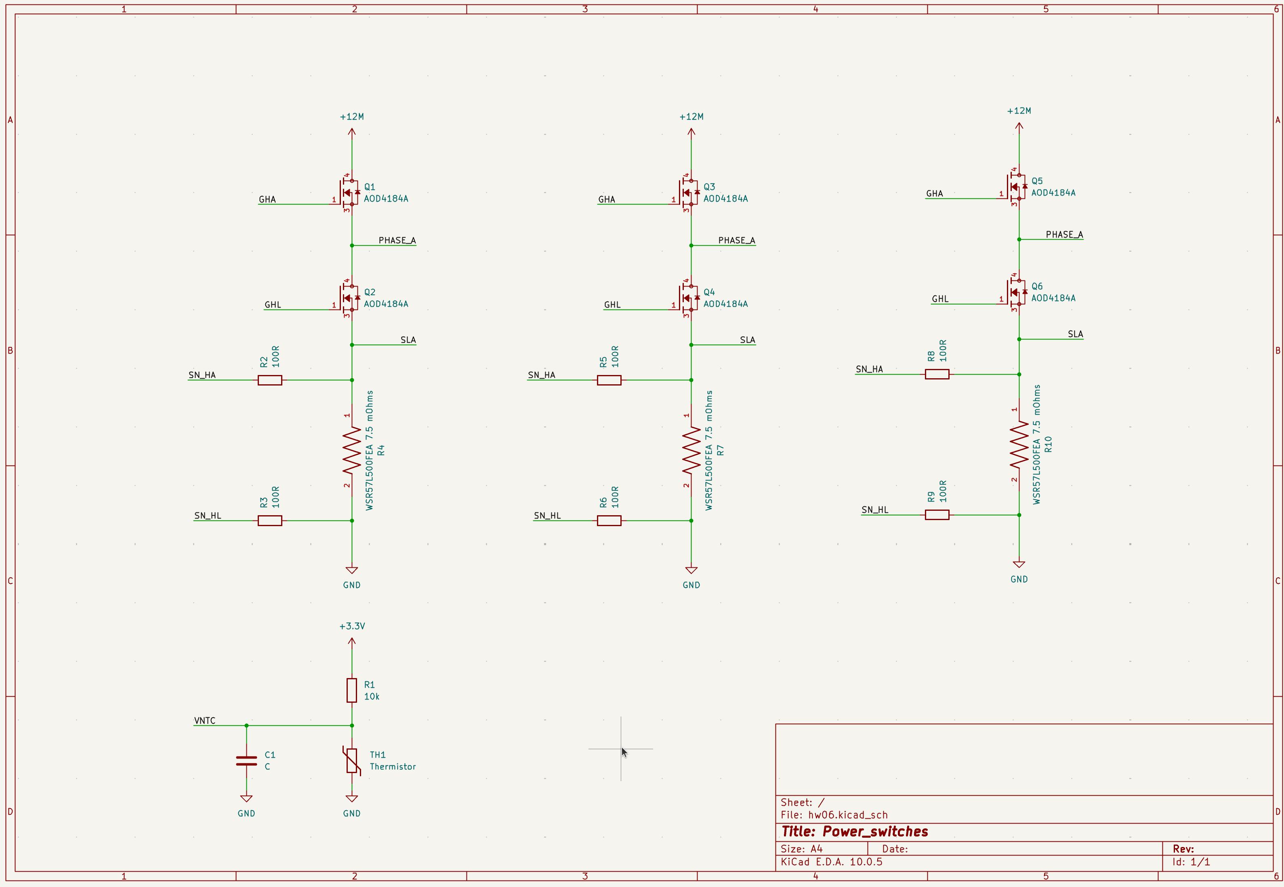
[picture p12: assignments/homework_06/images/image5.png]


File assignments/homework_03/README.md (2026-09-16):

# Заняття 3: Компонентна база: пасивні та активні компоненти.

### Завдання 1

1\. Варіант 1: Розрахуйте резистор для світлодіода SMD 2835 0,2 W

Знайшов його datasheet: <https://www.bridgelux.com/sites/default/files/ds1458.pdf>

Для нього характерні такі показники:

- Drive Current (mA): 20

- Forward Voltage (V): 2.64

Якщо напруга в нас 3.3 В, то розраховуємо резистор:

Віднімаємо від вхідної напруги значення Forward Voltage, отримуємо 3.3-2.64=0.66 В.

Для обмеження струму 20 мА потрібен наступний опір резистора:

U = R \* I --\> R = U/I = 0.66/0.02 = 33 Ом

Розрахуємо потужність резистора:

P = U \* I = 0.66 \* 0.02 = 0.0132 Вт — підійде резистор любої потужності, наприклад 0.125 Вт.

1\. Варіант 2: Розрахуйте резистор для світлодіода SMD 2835 SPMWH1228FD5WARUVG, напруга живлення 3,3 В, необхідна відносна потужність світлового потоку — 10% (забезпечується 10 мА).

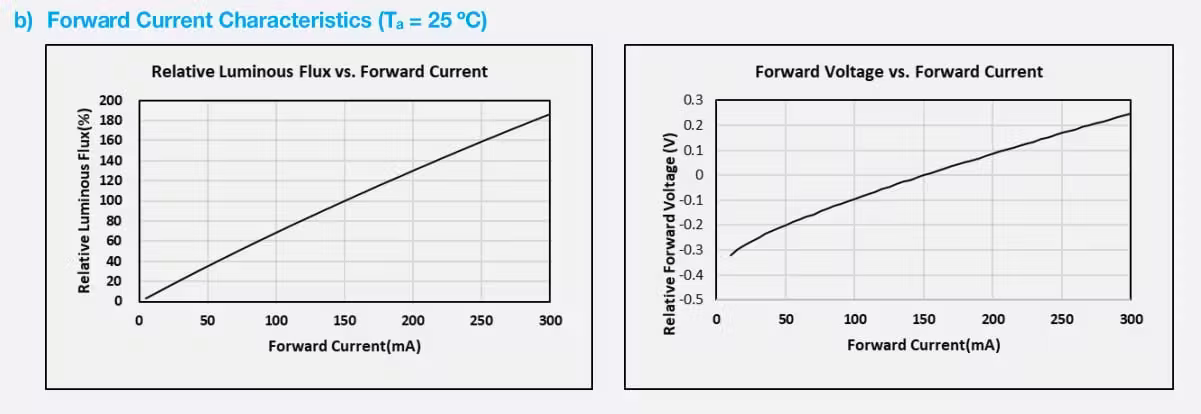
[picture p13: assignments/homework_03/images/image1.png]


Його datasheet знаходиться [тут](https://docs.superhuman.com/d/Hardware-Development_d5LyHpQBKAp/3_suPyynB0#_lubhjPNX).

Для нього характерні такі показники:

- Product Code Information - SPMWH1228FD5WARUVG

| | | | |
|:---:|:---:|:---:|:---:|
| **Digit** | **PKG Information** | **Code** | **Specification** |
| 1 2 3 | Samsung Package Middle Power | SPM | Middle Power |
| 4 5 | Color | WH | White |
| 6 | Product Version | 1 | Without Zener |
| 7 8 9 | Form Factor | 228 | 2.8 x 3.5 x 0.7; 2 pads  |
| 10 | Sorting Current (mA) | F | 150 mA |
| 11 | Chromaticity Coordinates | D | ANSI Standard |
| 12 | CRI | 5 | Min. 80 |
| 13 14 | Forward Voltage (V) | WA | 2.8-3.1, 4000ea per reel |
| 15 16 | CCT (K) | RU | 5000 |
| 17 18 | Luminous Flux | VG | VG |

- Sorting Current (mA): 150

- Forward Voltage V<sub>F</sub> (V): Bin нам невідомий, тому вибираємо середнє значення між 2.8 - 3.1 = 2.95

Якщо напруга в нас 3.3 В, то розраховуємо резистор:

Віднімаємо від вхідної напруги значення Forward Voltage V<sub>F</sub>, отримуємо 3.3-2.95=0.35 В.

Для обмеження струму 10 мА потрібен наступний опір резистора:

U = R \* I --\> R = U/I = 0.35/0.01 = 35 Ом. Вибираємо найближчий більший номінал = 36 Ом.

Розрахуємо потужність резистора:

P = I<sup>2</sup> \* R = 0.01 \* 0.01 \* 36 = 0.0036 Вт — множимо на 2 і отримуємо 72 мВт. Вибираємо корпус по таблиці: SMD 0603 потужністю 0.1 Вт.

2\. Розрахуйте подільник напруги 12 В → 3 В (струм 40 мА)

Розраховуємо суму опору дільника в цілому: R = U/I = 12/0.04 = 300 Ом

Розраховуємо опір нижнього резистора: Rн = U/I = 3/0.04 = 75 Ом

Розраховуємо опір верхнього резистора: Rв = R - Rн = 300 - 75 = 225 Ом

### Завдання 2 — INA301A2

Дано підсилювач [INA301A2 (datasheet TI)](https://www.ti.com/lit/ds/symlink/ina301.pdf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).

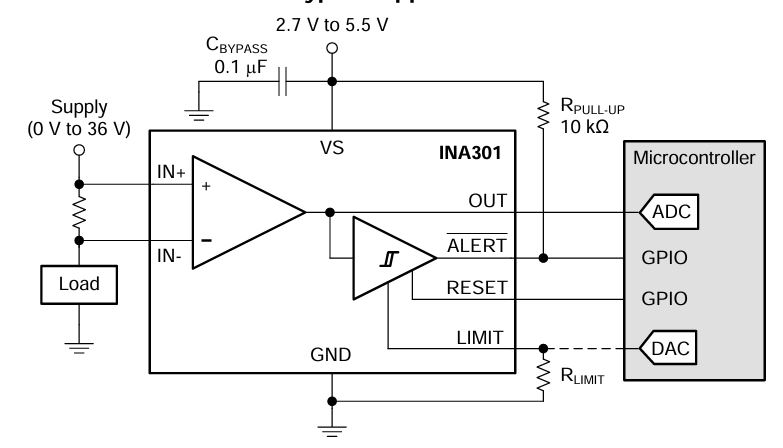
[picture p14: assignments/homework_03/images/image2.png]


Розрахуйте шунт (опір і корпус відповідно до розсіюваної потужності) для виміру струму навантаження, який максимально може бути 2 А. Напруга живлення навантаження — 12 В, напруга живлення підсилювача/MCU — 3,3 В. Додатково розрахуйте RLIMIT.

Подивимося на datasheet.

Напруга живлення навантаження 12 В списується в діапазон вхідної напруги: від 0 В до 36 В.

- Коефіцієнт підсилення напруги мікросхеми (Voltage Gain): 50 V/V.

При живленні VS = 3.3 В вихід INA301 не доходить гарантовано до 3.3 В. Datasheet дає swing до позитивної шини приблизно VS - 0,05 V типово і VS - 0,1 V у гіршому випадку. Крім того, параметри gain error та nonlinearity нормуються в області лише від 0,5 V до VS - 0,5 V. Тому для коректного вимірювального розрахунку краще закладати верхню робочу напругу близько Vout = 3.3 - 0.5 = 2.8 V.

- Згідно datasheet максимальна диференційна напруга на вході дорівнює = 100 мВ = 0.1 В. Але в нашій схемі робочий діапазон буде меншим через живлення 3.3 В. При розрахунку від Vout розрахункова диференційна напруга на вході дорівнює V in max = Vout/Gain = 2.8/50 = 0.056 В (беремо менше значення з двох - 0.056 В та 0.1 В).

- Максимальне падіння напруги на шунті дорівнює V sense = V in max = 0.056 В.

- Розраховуємо опір шунта: R sense = V in max/I load = 0.056/2 = 0.028 Ом. Вибираємо стандартне значення R sense = 0.027 Ом.

- Розраховуємо розсіювану потужність: P sense = Imax<sup>2</sup> \* R sense = 2<sup>2</sup> \* 0.027 = 0.108 Вт. Реальну потужність потрібно забезпечити з запасом – помножимо на 2. P sense = 0.108 \*2 = 0.216 Вт.

- Корпус резистора дивимося в таблиці (SMD Resistor Power Rating Chart (0201 to 2512 Packages)) на сайті <https://jlcpcb.com/blog/resistor-power-rating> - найближчий резистор що підійде - потужністю 0.25 Вт, але для шунта я би взяв з запасом — потужністю 0.5 Вт: SMD 1210.

- Для розрахунку R limit виконуємо розрахунок згідно таблиці внизу що буде дорівнювати 37500 Om. Серед найближчих з точністю E96 підходять значення 33.2 kOm та 34 kOm. Якщо вибирати 33.2 kOm, то сигнал помилки спрацює раніше за максимальний струм в 2 А і буде дорівнювати 1.97 А (розрахунок під таблицею), що менше граничного значення на -1.5%. Якщо поставити більше значення 34 kOm, то значення струму перевищить 2 А і буде дорівнювати 2.02 А, що означає перевищення граничного значення на 1%. Правильне рішення - вибираємо значення 33.2 kOm з резисторів точністю E96 тому що струм краще обмежувати знизу і не перевищувати максимальне значення 2 А. В даному випадку при струмі 1.97 А спрацює інверсний вихід сповіщення ALERT що дозволить швидко виявити подію перевантаження по струму.

<table>
<colgroup>
<col style="width: 9%" />
<col style="width: 55%" />
<col style="width: 35%" />
</colgroup>
<tbody>
<tr>
<td colspan="2" style="text-align: center;"><strong>PARAMETER</strong></td>
<td style="text-align: center;"><strong>EQUATION</strong></td>
</tr>
<tr>
<td rowspan="2" style="text-align: center;">V trip</td>
<td rowspan="2" style="text-align: center;">V out at the desired current trip value<br />
Порогова напруга захисту</td>
<td style="text-align: center;">I load * R sense * Gain</td>
</tr>
<tr>
<td style="text-align: center;">2 A * 0.027 Ом * 50 V/V = 2.7 V</td>
</tr>
<tr>
<td rowspan="2" style="text-align: center;">V limit</td>
<td rowspan="2" style="text-align: center;"><p>Threshold limit voltage</p>
<p>Порогова напруга обмеження</p></td>
<td style="text-align: center;">V limit = V trip</td>
</tr>
<tr>
<td style="text-align: center;">2.7 V</td>
</tr>
<tr>
<td rowspan="2" style="text-align: center;">I limit</td>
<td rowspan="2" style="text-align: center;"><p>Limit threshold output current</p>
<p>Граничний вихідний струм</p></td>
<td style="text-align: center;">I limit from datasheet</td>
</tr>
<tr>
<td style="text-align: center;">80 мкА</td>
</tr>
<tr>
<td rowspan="2" style="text-align: center;">R limit</td>
<td rowspan="2" style="text-align: center;"><p>Calculate the threshold limit-setting resistor</p>
<p>Розрахувати резистор, що задає поріг обмеження</p></td>
<td style="text-align: center;">V limit / I limit</td>
</tr>
<tr>
<td style="text-align: center;">2.7 V / 0.00008 A = 33750 Om</td>
</tr>
</tbody>
</table>

**Розрахунок струму через навантаження при R limit = 33.2 kOm:**

V trip = I load \* R sense \* Gain

V limit = V trip

R limit = V limit / I limit = V trip / I limit = I load \* R sense \* Gain / I limit

R limit = I load \* R sense \* Gain / I limit

R limit \* I limit = I load \* R sense \* Gain

I load \* R sense \* Gain = R limit \* I limit

Тоді значення I load можна порахувати наступним чином:

I load 33.2к = R limit \* I limit / (R sense \* Gain) = 33200 Om \* 0.00008 A / (0.027 Om \* 50 V/V) = 1.97 А

Відхилення від максимального струму навантаження = (I load 33.2к - I load) / I load \* 100% = (1.97 – 2) / 2 \* 100 = -1.5%.

**Розрахунок струму через навантаження при R limit = 34 kOm:**

I load 34к = R limit \* I limit / (R sense \* Gain) = 34000 Om \* 0.00008 A / (0.027 Om \* 50 V/V) = 2.02 А

Відхилення від максимального струму навантаження = (I load 34к - I load) / I load \* 100%= (2.02 – 2) / 2 \* 100 = 1%.

### Завдання 3 — BZX84WC

Паралельно до навантаження стоїть [BZX84WC15V (datasheet TI)](https://www.ti.com/lit/ds/symlink/bzx84wc15v.pdf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). На навантаженні має бути **15 В**, струм min **1 мА**, max **2 мА**.

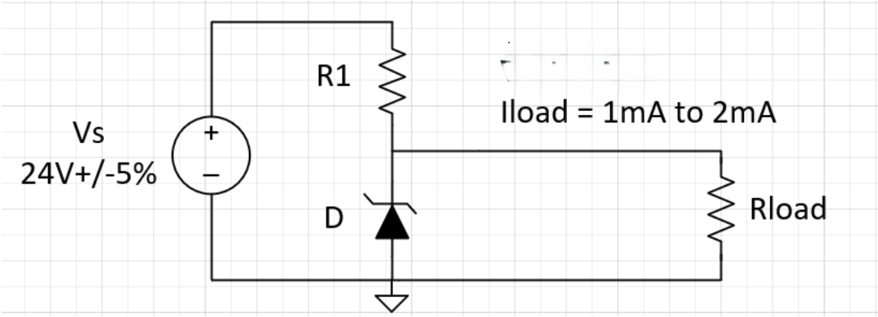
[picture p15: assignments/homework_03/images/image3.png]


Розрахуйте номінал і корпус резистора R1, перевірте, чи підходить стабілітрон по потужності.

BZX84WC15V:

|  |  |  |  |
|:--:|:--:|----|----|
| Zener VoltageVZ (V) at IZ | Напруга стабілітрона (В) | MIN | 14.25 |
|  |  | TYP | 15.00 |
|  |  | MAX | 15.75 |
|  |  | IZ (mA) | 5.00 |
| Zener ImpedanceZZT (Ω) at IZ | Опір стабілітрона (Ом) | MAX | 30.00 |
|  |  | IZ (mA) | 5.00 |
| Reverse Leakage CurrentIR (μA) | Зворотний струм витоку (мкА) | MAX | 0.03 |
|  |  | VR (V) | 10.50 |
| Temperature CoefficientSZ (mV/C) at IZ | Температурний коефіцієнт (мВ/C) | MAX | 13.00 |
|  |  | IZ (mA) | 5.00 |
| CapacitanceC D (pF) | Ємність (пФ) | MAX | 50.00 |

1.  Визначення діапазону вхідної напруги

Вхідна напруга Vs = 24 V +/- 5%:

- Мінімальна напруга Vs min = 24 \* 0.95 = 22.8 V

- Максимальна напруга Vs max = 24 \* 1.05 = 25.2 V

Напруга на стабілітроні (і навантаженні) становить Vz = 15 V.

2.  Розрахунок номіналу резистора R1

    Струм через навантаження Iload = {.min = 1mA, .max = 2mA}. Для стабільної роботи стабілітрона через нього повинен проходити певний мінімальний струм. В даному випадку нам потрібно використовувати струм Iz = 5 mA з datasheet при якому надаються основні параметри стабілітрона. Розглянемо коли Iz = 5 mA.

    Проробляємо найгірший сценарій для стабілізації коли вхідна напруга мінімальна (Vs min = 22.8 V), а струм навантаженні - максимальний (Iload max = 2mA).

- Струм через резистор R1 в найгіршому випадку:
  I<sub>R1 MAX</sub> = Iz + Iload max = 5 + 2 = 7 mA.

- Максимально допустимий опір R1:
  R1 max = (Vs min - Vz) / I<sub>R1 MAX</sub> = (22.8 - 15) / 0.007 = 1114.29 Om. Оскільки номінал має бути меншим або дорівнювати 1.114 kOm, обираємо найближче менше стандартне значення з ряду E24.

- Вибраний номінал R1: 1.1 kOm.

3.  Перевірка стабілітрона та резистора по потужності

    Проведемо перевірку в режимі максимального навантаження – максимальною напругою на вході (Vs max = 25.2 V) і максимальним струмом навантаження (Iload_max = 2mA). Зробимо розрахунок для вибраного номінала резистора R1 = 1.1 kOm:

- Максимальний струм через резистор:
  I<sub>R1 MAX</sub> = (Vs max - Vz) / R1 = (25.2 V - 15 V) / 1100 Om = 0.0093 = 9.3 mA.

- Максимальний струм через стабілітрон:
  I<sub>Z MAX</sub> = I<sub>R1 MAX</sub> - Iload min = 9.3 mA - 1mA = 8.3 mA.

- Максимальна потужність що розсіюється на стабілітроні:
  P<sub>Z MAX</sub> = Vz \* I<sub>Z MAX</sub> = 15 V \* 8.3 mA = 15 \* 0.0083 = 0.1245 Вт ≈ 125 мВт.

- Максимальна потужність на резисторі R1:
  P<sub>R1 MAX</sub> = (Vs max - Vz) / I<sub>R1 MAX</sub> = (25.2 V - 15 V) / 9.3 mA = 0.09486 Вт ≈ 95 мВт.

4.  Вибір корпусів компонентів:

- **Стібілітрон BZX84WC15V:** поставляється в корпусі SC-70 і має максимальну розсіювану потужність 360 мВт і може витримувати потужність 125 мВт що необхідна для нашої схеми.

- **Резистор R1:** оскільки максимальна потужність на ньому становить 95 мВт а з запасом в 2 рази це буде 0.19 Вт, то вибираємо такий тип корпусу що витримує необхідну потужність - SMD 1206 на 0.25 Вт.

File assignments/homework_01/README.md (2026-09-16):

# Заняття 1: Робоче середовище, пошук компонента (datasheet, символ, footprint, 3D)

Скріншот головного вікна:

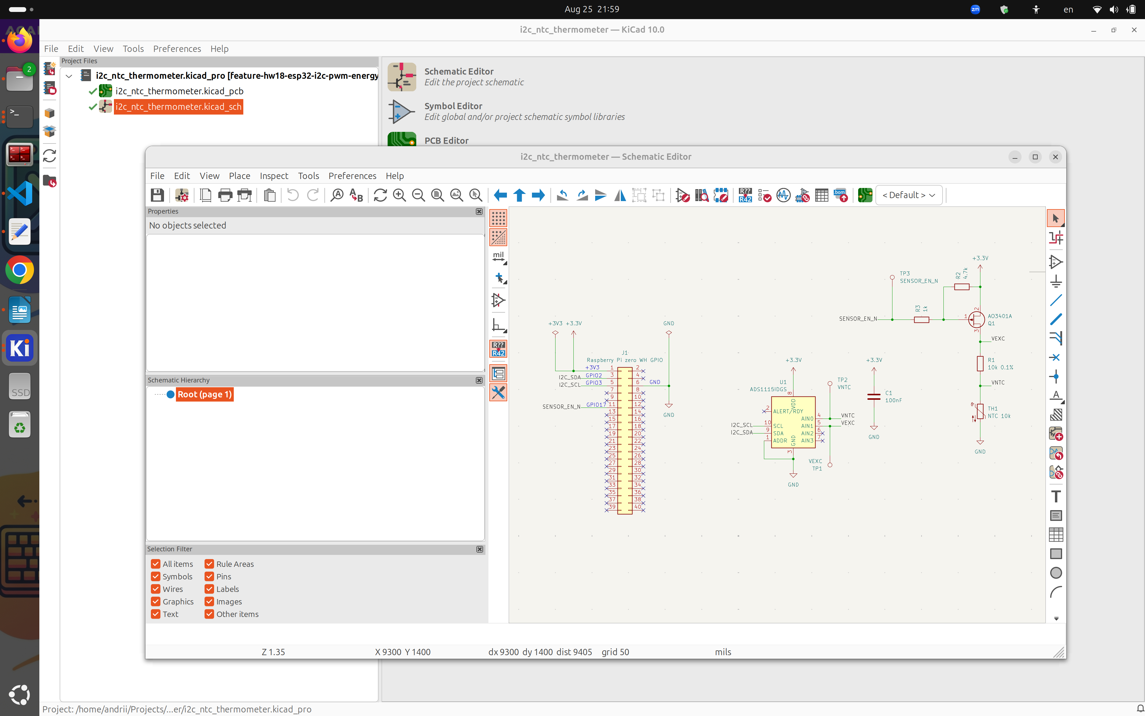
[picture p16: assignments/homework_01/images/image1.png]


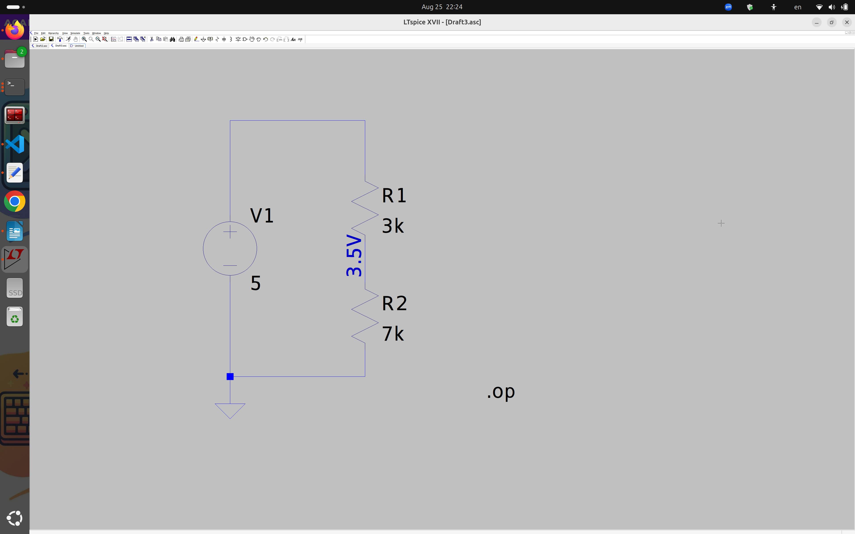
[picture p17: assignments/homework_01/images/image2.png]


Microchip ATTINY13A-SSH

1\. Datasheet (Технічний опис)

<https://octopart.com/datasheet/microchip/ATTINY13A-SSH>

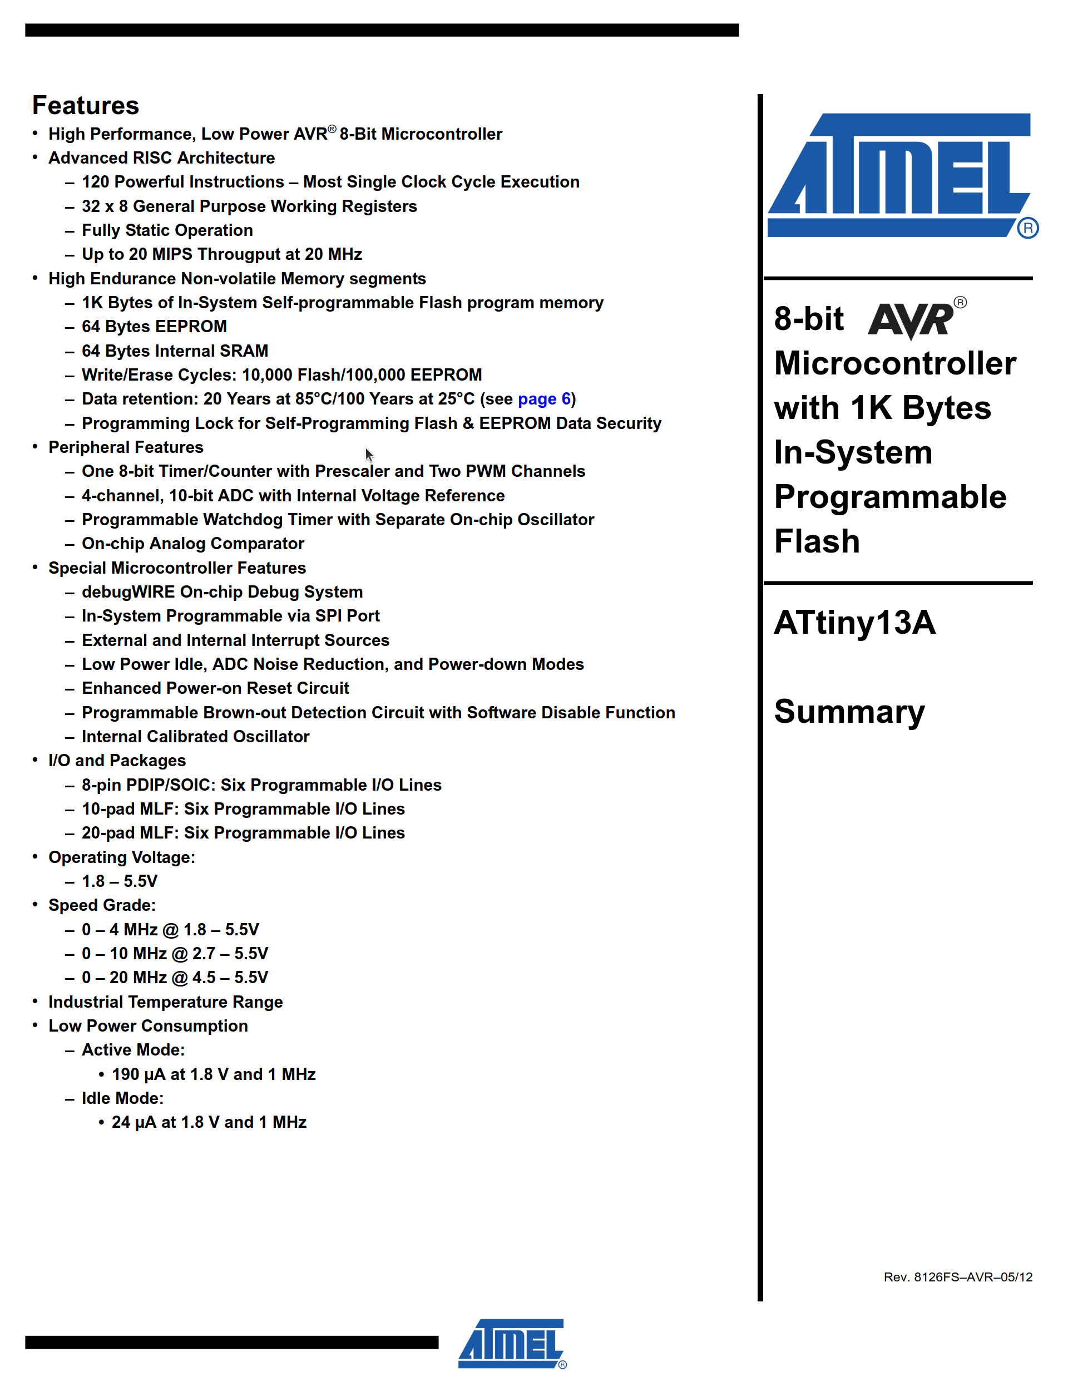
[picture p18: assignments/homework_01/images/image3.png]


2\. Схематичний символ (Schematic Symbol)

<https://www.snapeda.com/parts/ATTINY13A-SSH/Microchip/view-part/>

3\. PCB Footprint (Посадкове місце на платі)

<https://www.snapeda.com/parts/ATTINY13A-SSH/Microchip/view-part/>

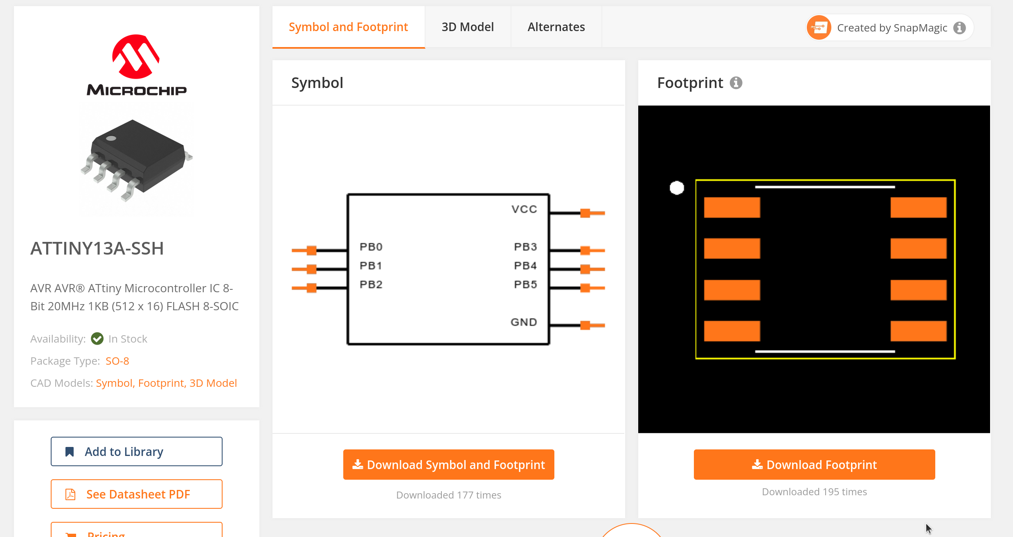
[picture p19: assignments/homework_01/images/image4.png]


4\. 3D Model (STEP)

<https://www.snapeda.com/parts/ATTINY13A-SSH/Microchip/view-part/>

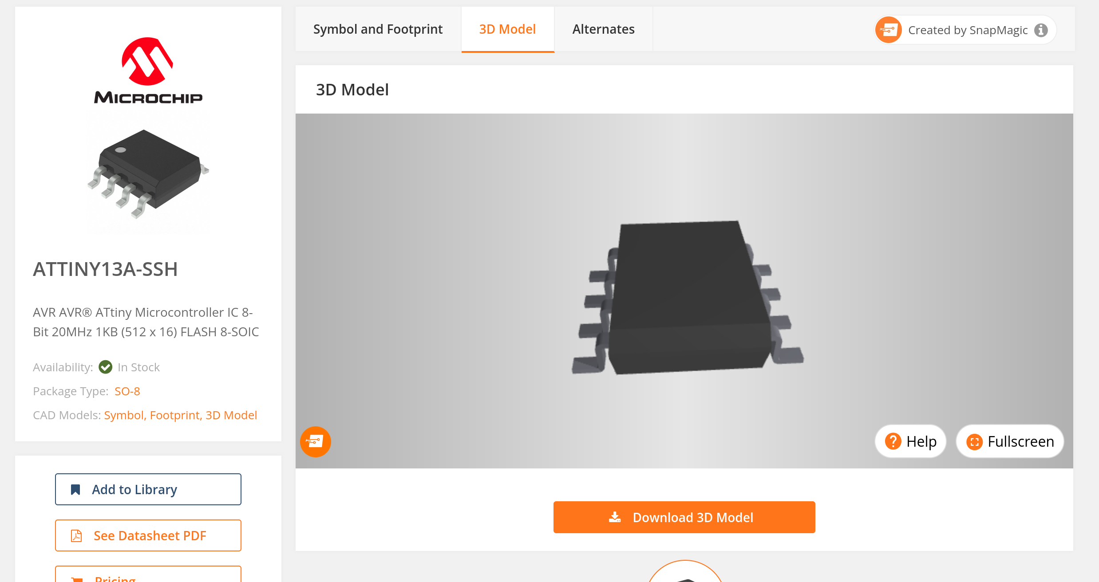
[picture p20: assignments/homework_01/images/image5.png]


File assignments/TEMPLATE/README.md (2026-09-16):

# Заняття N: <тема>

## Завдання 1: <назва>

**Умова.** <коротко, своїми словами або цитата>

**Рішення.**

<розрахунок; формули можна писати як $C_{ext} = 2 (C_L - C_s)$ — GitHub їх рендерить>

Симуляція

Файли: [`schematic.asc`](schematic.asc),
[`inverter.kicad_sch`](../../motor-drive-controller/hardware/kicad/inverter.kicad_sch)

**Висновок.** <відповідь з одиницями виміру та запасами>

## Завдання 2: <назва>

...

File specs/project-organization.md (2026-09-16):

Дій як фахівець з великим стажем - з електроніки, програмування з підвищеними вимогами до реалізації - надійності, якості через використання результату в відповідальних проектах,
від яких залежить життя людей. Ти знаєшся на сучасних технологіях.
Цей проект в першу чергу призначено для проходження навчального курсу "Hardware Development: від схеми до прототипу". Ось посилання на презентацію 
https://drive.google.com/file/d/1CE6x6IZQDqLbA8KuolooOyTGvIyJnZ77/view.

Я скоро буду доходити до середини курсу, але вирішив впорядкувати роботу з цим курсом. Якщо раніше звітував про виконанне завдання за допомогою документа *.docx що завантажувався на навчальний сайт, то зараз я хочу перейти до кращих практик - ведення проекту по розробці в git репозиторії. Я вже створив репозиторій https://github.com/anhro/hardware-development вже є первинна гілка master але потрібно впорядкувати файли. Не всі файли потрібно завантажувати. Взагалі потрібно твоя допомога щоб мінімізувати зусилля на підтримку та максимум автоматизувати процеси. Мабуть було б корисно формувати документи в markdown форматі, тримати зображення окремо а потім за необхідності генерувати *.docx документ як звіт для виконання завдання. Можливо зможу домовитися робити посилання на pull request в репозиторії де викладач зможе краще подивитися на результат (тільки потрібно показати як просто користуватися репозиторієм, як вивантажити на локальний диск, де дивитися результати).

Допоможи розібратися які додатки краще використовувати (для мінімальної кількості змінених файлів в репозиторії - перевага текстовим файлам). Я працюю зараз в KiCad, LTspice, STM32CudeMX та STM32CudeIDE (можливо заміню його на VS Code). Якщо потрібно змінити додаток на більш сучасний я готовий на це подивитися.
В директорії можуть знаходитися поточні файли datasheets які не потрібно завантажувати в репозиторій (як і багато іншіх бінарників), але було б непогано щоб однією командою можна було відновити їх при клонуванні репозиторія в конкретний директорій @motor-drive-controller/hardware/datasheets

Взагалі правило таке - мінімум файлів та їх змін, відсутність дублікатів та бінарників (по можливості).

Я вже створив структуру на диску (перша ітерація). В @assignments знаходяться необроблені файли що я використовував для виконання домашніх завдань. Чи потрібно їх якось конвертувати в заливати в git - я не знаю.

В @motor-drive-controller знаходиться сам проект курса, що поступово буде ускладнюватися та доповнюватися
В @motor-drive-controller/hardware/kicad знаходиться поточна версія проекту KiCad - це 7 завдання.
В @motor-drive-controller/firmware знаходиться поточна версія проекту STM32CudeMX - це також 7 завдання. Там багато згенерованих файлів через конфігурацію і я не знаю чи потрібно їх всі завантажувати.
Документи не заповнені.

Твоя задача допомогти організувати цей навчальний проект та привести його у систему і настроїти всі як навчальні процеси, так і процеси розробки.

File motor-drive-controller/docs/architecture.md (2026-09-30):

# Архітектура

Стан схеми після ДЗ 8. Суцільні лінії — з'єднання, що вже є на схемі;
пунктирні — заплановані або ще не підключені (див. [відкриті питання](design-notes.md#відкриті-питання)).

## Сигнали

```mermaid
flowchart LR
    HSE["Кварц 8 МГц"] --> MCU
    DBG["JTAG/SWD"] --- MCU
    HALL["Датчики Холла<br/>роз'єм J4"] -- "HALL1–3 → PC6–PC8 (FT)" --> MCU

    MCU["<b>MCU</b><br/>STM32F405RGT6<br/>168 МГц"]
    DRV["<b>Gate Driver</b><br/>DRV83053PHP<br/>підсилювачі струму, LDO 3.3 В"]
    INV["<b>Inverter</b><br/>3× напівміст AOD4184A<br/>шунти 7.5 мОм, NTC"]

    MCU -- "INHA…INLC<br/>TIM1 CH1–3 / CH1N–3N" --> DRV
    DRV -- "nFAULT → PC4<br/>PWRGD → PC5" --> MCU
    MCU -. "SPI, EN_GATE, WAKE" .-> DRV
    DRV -. "SO1–3 → ADC" .-> MCU
    DRV -. "GHx / GLx" .-> INV
    INV -. "SHx, SN / SP" .-> DRV
    INV -- "TEMP_SENSE → PC0 (ADC1_IN10)" --> MCU
    INV --> M(("BLDC"))
```

Між листами сигнали поки позначені локальними мітками, тому в KiCad вони ще
не з'єднані електрично (див. ERC). На діаграмі показано задумане з'єднання.

## Живлення

```mermaid
flowchart LR
    V12["+12M<br/>живлення двигуна"] --> PVDD["DRV8305<br/>PVDD, VDRAIN (100 Ом)"]
    V12 --> Q["Стоки верхніх ключів<br/>AOD4184A"]
    PVDD --> VREG["VREG<br/>LDO 3.3 В"]
    VREG --> V33["+3.3V"]
    V33 --> MCUP["STM32F405<br/>VDD, VDDA (через FL1)"]
    V33 --> PU["Підтяжки nFAULT/PWRGD<br/>JTAG VTREF"]
    BAT["CR2032"] --> VBAT["VBAT MCU"]
    V5["+5V<br/>(джерела немає)"] -.-> HALL["Датчики Холла"]
```

Уся шина +3.3V живиться від VREG драйвера — запас струму й поведінку VREG
у режимі sleep / при аварії треба перевірити до розведення плати.

## Ключові рішення

| Вузол | Рішення | Обґрунтування |
|---|---|---|
| Силові ключі | AOD4184A, 40 В / 50 А, 5.8 мОм, TO-252 | [ДЗ 6](../../assignments/homework_06/README.md) |
| Шунти | WSR57L500FEA, 7.5 мОм, 5 Вт | [ДЗ 6](../../assignments/homework_06/README.md) |
| MCU | STM32F405RGT6: TIM1 з комплементарним ШІМ і dead-time, 3 ADC | [ДЗ 7](../../assignments/homework_07/README.md) |
| Тактування | HSE 8 МГц (AAH-181), C<sub>ext</sub> = 30 пФ, PLL → 168 МГц | [ДЗ 7](../../assignments/homework_07/README.md) |
| Драйвер затворів | DRV83053PHP: вбудовані підсилювачі струму та LDO 3.3 В, SPI | [ДЗ 8](../../assignments/homework_08/README.md) |
| Датчики Холла | PC6–PC8: FT-піни, водночас TIM3_CH1–CH3 (апаратний інтерфейс Холла) | [ДЗ 8](../../assignments/homework_08/README.md) |

Детально — у [`design-notes.md`](design-notes.md).

## Вимоги

| Параметр | Значення | Джерело |
|---|---|---|
| Напруга живлення | 12 В | ДЗ 6 |
| Потужність двигуна з навантаженням | 168 Вт (~14 А) | ДЗ 6 |
| Запас ключів за струмом / напругою | ≥ 1.5–2× / ≥ 1.5–2× (комфортно 3×) | ДЗ 6 |
| Максимальна напруга сигналу струму на вході АЦП | 3.3 В | ДЗ 6 |
| Підсилення сигналу струму | 20 В/В (задається в DRV8305 через SPI) | ДЗ 6, 8 |
| Живлення логіки драйвера | +3.3V; VDRAIN — від +12M | ДЗ 8 |

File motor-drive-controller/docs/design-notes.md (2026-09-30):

# Інженерні рішення та відкриті питання

Журнал рішень: що вибрано, чому, і що треба перевірити. Нові записи — зверху.

## Відкриті питання

Для силової електроніки ці пункти критичні — закрити до розведення плати /
першого увімкнення. Стан перевірено за нетлистом і ERC гілки `hw08`.

### ДЗ 8 — драйвер DRV8305

- [ ] **Живлення MCU залежить від стану драйвера.** Шина +3.3V (VDD MCU, JTAG,
  підтяжки) живиться лише від виходу VREG драйвера (U3.48), іншого джерела
  3.3 В на схемі немає. Перевірити за даташитом:
  - максимальний струм VREG проти споживання STM32F405 на 168 МГц
    (десятки мА, з усією периферією — до ~90 мА) плюс навантаження шини;
  - поведінку VREG у режимі sleep і при аварії драйвера. Якщо VREG вимикається,
    MCU втратить живлення й не зможе ні вивести драйвер зі сну, ні прочитати
    причину аварії.

  Якщо запасу немає — окремий LDO 3.3 В від +12M для MCU, а DRV8305
  обрати у версії N (без VREG) або лишити VREG лише для самого драйвера.
- [ ] **WAKE і EN_GATE не підключені.** WAKE (U3.47) виводить драйвер зі сну,
  EN_GATE (U3.1) вмикає вихідні каскади затворів. Непідключені — драйвер не
  керує ключами. EN_GATE завести на GPIO MCU (керований безпечний старт:
  спочатку конфігурація, потім EN_GATE = 1); WAKE — на GPIO або підтяжку
  відповідно до обраної схеми живлення (див. пункт вище).
- [ ] **Exposed pad (U3.49) не з'єднаний з GND.** Нет `EP` містить лише пади
  корпусу. Термопад HTQFP-48 має бути на GND з масивом переходів у полігон —
  інакше драйвер перегріється, а заземлення буде неповним.
- [ ] **SPI не підключено** (SCLK, SDI, SDO, nSCS — U3.9–U3.12). Без SPI не можна
  прочитати регістри статусу (причину nFAULT) і налаштувати драйвер (dead-time,
  струм затвора, пороги VDS, коефіцієнт підсилення CSA). Завести на SPI MCU
  (наприклад, SPI2 або SPI3).
- [ ] **Виходи підсилювачів струму SO1–SO3 не підключені.** Завести на входи ADC.
  Узгодити з розрахунком ДЗ 6: там закладено підсилювач 20 В/В — у DRV8305
  коефіцієнт CSA задається через SPI, тож треба вибрати відповідний і перевірити,
  що при 21 А сигнал не перевищує 3.3 В.
- [ ] **Міжлистові з'єднання не існують електрично.** Сигнали INHA…INLC,
  DRV_nFAULT, DRV_PWRGD позначені *локальними* мітками на листах MCU і Gate
  Driver — KiCad вважає їх різними колами (`/MCU/INHA` ≠ `/Gate Driver/INHA`).
  Те саме з GHx/GLx/PHASE_x/SN_xx між Gate Driver та Inverter. Потрібні
  ієрархічні мітки з пінами листів (або глобальні мітки).
- [ ] **nFAULT → апаратне вимкнення ШІМ.** Зараз nFAULT іде на звичайний GPIO PC4.
  Розглянути підключення до TIM1_BKIN — вільний пін **PA6** (альтернатива PB12):
  тоді аварія драйвера (у т. ч. спрацювання захисту VDS) миттєво вимикає
  всі виходи TIM1 без участі програми.
- [ ] **Датчики Холла.** Роз'єм J4 живить датчики від **+5V**, але джерела +5 В на
  схемі немає. Холли зазвичай мають вихід з відкритим колектором — потрібні
  підтяжки (зовнішні до 3.3 В/5 В або внутрішні GPIO; зараз `GPIO_NOPULL`) і
  RC-фільтр від завад з боку силової частини.
- [ ] **ERC: 123 порушення** (73 error, 50 warning): 45 ізольованих міток,
  41 непідключений пін, 23 не керовані входи, 9 не керованих power-пінів,
  4 конфлікти імен кіл. Більшість — наслідок пунктів вище.

### ДЗ 7

- [x] **Тактування не відповідає схемі.** Виправлено: HSE = 8 МГц,
  PLL (M = 4, N = 168, P = 2) → SYSCLK 168 МГц.
- [ ] **Dead-time TIM1 = 0, Break вимкнено.** DRV8305 має власний dead-time і
  захист від одночасного відкриття ключів напівмоста (перевірити режим вхідного
  ШІМ і налаштування за даташитом), але dead-time TIM1 варто задати не меншим,
  ніж у драйвері, — захист на двох рівнях. Увімкнути BKIN (див. nFAULT вище),
  вихідні стани OSSI/OSSR — ключі закриті. Канал АЦП насичується на ~22 А
  (3.3 В), тож захист від КЗ має бути апаратним (VDS-монітор драйвера /
  компаратор → BKIN), а не програмним через АЦП.
- [x] **Звіт ДЗ 7 згадує кварц AAH-438-28.63636MHz-T3**, а розрахунок і схема —
  для AAH-181-8.000MHZ. Уточнити текст.
- [ ] **Частина символів без footprint** (конденсатори, резистори, кнопка,
  роз'єми) — призначити перед переходом до PCB (див. BOM, колонка Footprint).
- [ ] Datasheets без прямих посилань у `datasheets.txt`: BLM18AG331SN1D,
  AAH-181-8.000MHZ, Molex 1726486303, тримач CR2032.

## Рішення

### ДЗ 8 — драйвер затворів DRV8305

**Компонент: DRV83053PHP** — промислова версія (не -Q1), вбудований LDO 3.3 В
(цифра **3**), корпус HTQFP-48 (**PHP**) у лотках (без **R**, Tape & Reel не
потрібен). Бібліотека: `hardware/kicad/lib/parts/DRV83053PHP/` (SnapEDA).

**Зовнішні компоненти** — за таблицею *External Components* (ст. 5 даташиту),
лист [`gate-driver.kicad_sch`](../hardware/kicad/gate-driver.kicad_sch):

| Вивід | Компонент |
|---|---|
| CP1H–CP1L, CP2H–CP2L (накачка заряду) | C18, C19 — 47 нФ |
| VCPH | C21 — 2.2 мкФ |
| VCP_LSD | C23 — 1 мкФ |
| PVDD (+12M) | C20 — 4.7 мкФ |
| AVDD, DVDD, VREG | C24, C17, C16 — 1 мкФ |
| VDRAIN ← +12M | R12 — 100 Ом |
| nFAULT, PWRGD (open-drain) | R15, R16 — 10 кОм до +3.3V |

**Призначення пінів MCU** (`motor-drive-controller.ioc`):

| Сигнал | Пін MCU | Функція | DRV8305 |
|---|---|---|---|
| INHA / INLA | PA8 / PA7 | TIM1_CH1 / CH1N | 2 / 3 |
| INHB / INLB | PA9 / PB0 | TIM1_CH2 / CH2N | 4 / 5 |
| INHC / INLC | PA10 / PB1 | TIM1_CH3 / CH3N | 6 / 7 |
| DRV_nFAULT | PC4 | GPIO input | 8 |
| DRV_PWRGD | PC5 | GPIO input | 13 |
| HALL1–HALL3 | PC6–PC8 | GPIO input, FT | роз'єм J4 (3–5) |

**Датчики Холла на PC6–PC8.** Піни 5 V tolerant (FT) за даташитом STM32F405
(DM00037051, с. 48–61) — витримують 5-вольтові датчики. Ці ж піни — TIM3_CH1–CH3:
надалі можна перейти з GPIO на апаратний інтерфейс датчиків Холла таймера
(XOR входів CH1–CH3), який вимірює інтервал між комутаціями без переривань
на кожен фронт.

Детально: [ДЗ 8](../../assignments/homework_08/README.md).

### ДЗ 7 — кварц HSE

C<sub>L</sub> = 18 пФ, паразитна ємність C<sub>s</sub> ≈ 3 пФ →
C<sub>ext</sub> = 2·(C<sub>L</sub> − C<sub>s</sub>) = 30 пФ.
Детально: [ДЗ 7](../../assignments/homework_07/README.md).

### ДЗ 6 — силові ключі та шунти

- Ключі **AOD4184A** (40 В, 50 А, R<sub>DS(on)</sub> = 5.8 мОм, TO-252):
  запас за напругою 3.3×, за струмом ~3.5×; втрати при 25 А ≈ 3.6 Вт проти 6.25 Вт
  у IRL3705N.
- Шунти **WSR57L500FEA** (7.5 мОм, 5 Вт): при 21 А (14 А × 1.5) — 0.1575 В,
  після підсилювача 20 В/В — 3.15 В < 3.3 В.

Детально: [ДЗ 6](../../assignments/homework_06/README.md).

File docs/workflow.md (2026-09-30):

# Процес роботи та правила репозиторію

## Принципи

1. **У git — лише джерела.** Схеми, код, Markdown, маніфести. Усе, що можна
   згенерувати (PDF, BOM, `.docx`, прошивка) чи завантажити (datasheets), —
   генерує `make`/CI і в git не потрапляє (див. [`.gitignore`](../.gitignore)).
2. **Без дублікатів.** Одна річ — одне місце. Звіт посилається на файли
   проєкту, а не копіює їх. Попередні версії — це історія git і теги, а не
   папки `old/`, `v2/`, `*_old`.
3. **Відтворюваність.** Після `git clone && make setup` проєкт відкривається й
   збирається на будь-якій машині: жодних абсолютних шляхів (`/home/...`,
   `~/Downloads`), усі бібліотеки — в репозиторії з відносними шляхами `${KIPRJMOD}`.
4. **Зображення — лише там, де немає текстового джерела** (скріншоти, графіки
   симуляцій, фото). Схеми для звіту не скріншотити вручну — PDF генерує CI.

## Цикл домашнього завдання

```bash
git switch master && git pull
git switch -c hw08                     # гілка на завдання

# ... робота в KiCad / LTspice / CubeMX, звіт у assignments/homework_08/README.md
make hardware                          # перевірити ERC, подивитися PDF
make report HW=08                      # за потреби — .docx для навчального сайту

git add -A && git commit -m "hw08: ..." # дрібні осмислені коміти
git push -u origin hw08                # відкрити Pull Request на GitHub
```

Після перевірки: **Merge pull request**, потім зафіксувати версію тегом —
CI сам створить Release зі звітом `.docx`, PDF схеми та BOM:

```bash
git switch master && git pull
git tag -a hw08 -m "Заняття 8: ..." && git push origin hw08
```

Якщо наступне завдання почато раніше (гілку `hw09` створено від `hw08`),
після merge її достатньо перенести на оновлений `master` — коміти `hw08`
уже є в `master`, git їх пропустить:

```bash
git switch hw09
git rebase master
git push --force-with-lease            # якщо hw09 вже на GitHub
```

На навчальний сайт — посилання на PR або Release (і, якщо вимагається, `.docx`
з релізу).

Новий звіт починати з шаблону: `cp -r assignments/TEMPLATE assignments/homework_08`.

## Інструменти

| Задача | Інструмент | Формат у git | Коментар |
|---|---|---|---|
| Схема і плата | **KiCad 10** | `.kicad_sch/.kicad_pcb/.kicad_pro` (текст) | Найкращий вибір для git: текстові файли, `kicad-cli` для CI. Залишаємо. |
| Симуляція | **LTspice 24** | `.asc` (+ `.plt`) | Стандарт індустрії, моделі ADI. `.raw/.log/.net` — генеруються, ігноруються. Альтернатива для CI — ngspice (KiCad має вбудований), але переходити не обов'язково. |
| Конфігурація MCU | **STM32CubeMX** | `.ioc` (текст) | Єдине джерело правди для пінів/периферії. Генерувати **CMake**-проєкт. |
| Код, збірка, налагодження | **VS Code + STM32Cube for VS Code** | `CMakeLists.txt`, `CMakePresets.json` | Офіційне розширення ST; CMake-проєкт збирається й у CI. Замінює STM32CubeIDE (Eclipse, багато службових файлів). |
| Документи | **Markdown** (VS Code) | `.md` + `images/*.png` | GitHub показує одразу; `.docx` генерується pandoc'ом. |
| Діаграми | **Mermaid** у Markdown або **draw.io** (`*.drawio.svg`) | текст / SVG | Mermaid рендериться GitHub'ом; `.drawio.svg` редагується в VS Code і водночас є картинкою. |
| Розрахунки | Markdown з формулами або **Python**-скрипт | `.md` / `.py` | Замість `.xlsx`: diff видно, результат відтворюється. |
| Datasheets | `datasheets.txt` + `make datasheets` | маніфест | PDF не зберігаються. |

VS Code запропонує рекомендовані розширення з [`.vscode/extensions.json`](../.vscode/extensions.json).

## Компоненти KiCad

Кожна нестандартна деталь — окрема папка
`motor-drive-controller/hardware/kicad/lib/parts/<PART>/`:

```
lib/parts/AOD4184A/
├── AOD4184A.kicad_sym        # символ
├── AOD4184A.pretty/*.kicad_mod
└── AOD4184A.step             # 3D-модель (за наявності)
```

Додати нову деталь (наприклад, завантажену з SnapEDA / Ultra Librarian):

1. Розпакувати в `lib/parts/<PART>/` за схемою вище.
2. KiCad → *Preferences → Manage Symbol/Footprint Libraries → Project Specific*:
   додати з nickname `<PART>` і шляхом `${KIPRJMOD}/lib/parts/<PART>/...`.
3. Додати datasheet у `hardware/datasheets/datasheets.txt`.

Не додавати бібліотеки в **Global Libraries** і не посилатися на `~/Downloads` —
інакше проєкт не відкриється на іншому комп'ютері.

## Datasheets

```
# hardware/datasheets/datasheets.txt
AOD4184A.pdf   https://www.aosmd.com/res/datasheets/AOD4184A.pdf
```

`make datasheets` завантажує відсутні; `make datasheets-check` показує PDF,
що лежать у папці, але не описані в маніфесті. Деякі сайти (st.com, molex.com)
блокують автоматичні завантаження — тоді скрипт виведе посилання для ручного
завантаження.

## Великі файли

Git LFS наразі не потрібен: бінарних файлів мало і вони не змінюються.
Якщо з'являться фото/відео прототипу понад кілька МБ — стискати (JPEG/WebP)
або вмикати LFS для `*.jpg`, `*.mp4`.

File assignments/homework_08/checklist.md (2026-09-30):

# Заняття 8: перевірка за чеклістом PR

Стан гілки `hw08` на 18.09.2026. Перевірено автоматично: `make hardware`
(ERC, BOM), `make firmware` (чиста збірка з git у контейнері Ubuntu 24.04),
аналіз нетлиста та `.ioc`.

Позначки: ✅ виконано · ⚠️ частково · ❌ не виконано

## Звіт

- [x] ✅ **Звіт у Markdown оновлено, зображення в `images/`.**
  [`README.md`](README.md) містить розбір вибору компонента та 4 зображення
  (схема драйвера, MCU, Pinout View, FT-піни); усі посилання на картинки коректні.
- [x] ✅ **Рішення та відкриті питання внесені в `design-notes.md`.**
  Розділ «ДЗ 8 — драйвер затворів DRV8305» (компонент, зовнішні компоненти,
  призначення пінів) і 9 відкритих питань — у
  [`design-notes.md`](../../motor-drive-controller/docs/design-notes.md).

## Схема (KiCad)

- [x] ✅ **Нові компоненти в `lib/parts/`, підключені через `${KIPRJMOD}`, datasheet у маніфесті.**
  - ✅ `lib/parts/DRV83053PHP/`: символ, footprint у `DRV83053PHP.pretty/`, 3D-модель STEP
    (структура така сама, як в інших компонентів).
  - ✅ `sym-lib-table` і `fp-lib-table`: шляхи через `${KIPRJMOD}`, бібліотеки знаходяться (ERC без `footprint_link_issues`).
  - ✅ `datasheets.txt`: `DRV8305.pdf` ← ti.com.
  - ✅ Невикористаний footprint `motor-drive-controller.pretty/RESC6331X70N` і його
    бібліотеку видалено — усі footprint'и тепер лише в `lib/parts/`.
- [ ] ❌ **Усі компоненти мають номінал і footprint.**
  Номінали задані всім. Footprint є лише в 14 з 54 компонентів проєкту;
  на листі Gate Driver — тільки в U3 (DRV83053PHP). Без footprint: C16–C21,
  C23, C24, R12, R15, R16.
- [ ] ❌ **Сигнали між листами з'єднані ієрархічними/глобальними мітками.**
  INHA…INLC, DRV_nFAULT, DRV_PWRGD позначені *локальними* мітками на листах MCU
  і Gate Driver, тож для KiCad це різні кола (`/MCU/INHA` ≠ `/Gate Driver/INHA`).
  Так само не з'єднані GHx/GLx/PHASE_x/SN_xx з листом Inverter.
  Локальні мітки вимагало завдання (п. 5); для реальної плати потрібні ієрархічні.
- [ ] ⚠️ **ERC переглянуто: порушення виправлені або пояснені.**
  123 порушення (73 error, 50 warning): 45 ізольованих міток, 41 непідключений
  пін, 23 не керовані входи, 9 не керованих power-пінів, 4 конфлікти імен кіл,
  1 незавершений провід. Причини пояснені у `design-notes.md`, але не виправлені.

## Прошивка (CubeMX)

- [x] ✅ **Імена пінів у `.ioc` збігаються з мітками на схемі.**

  | Пін | `.ioc` (User Label) | Схема MCU | |
  |-----|--------|-----------|---|
  | PA8, PA9, PA10 | INHA, INHB, INHC (TIM1_CH1–CH3) | INHA, INHB, INHC | ✅ |
  | PA7, PB0, PB1 | INLA, INLB, INLC (TIM1_CH1N–CH3N) | INLA, INLB, INLC | ✅ |
  | PC4 | DRV_nFAULT | DRV_nFAULT | ✅ |
  | PC5 | DRV_PWRGD | DRV_PWRGD | ✅ |
  | PC6–PC8 | HALL1–HALL3 | HALL1–HALL3 | ✅ |

  Ті самі імена є в коді: `INHA_Pin`…`INLC_Pin` у `main.h`, використовуються
  в `HAL_TIM_MspPostInit` (`stm32f4xx_hal_msp.c`).
- [x] ✅ **Код перегенеровано, прошивка збирається.**
  `main.h` містить визначення `DRV_nFAULT_Pin`, `HALL1_Pin`…, `MX_GPIO_Init`
  ініціалізує GPIOC як входи. `make firmware`: без помилок,
  FLASH 11 252 Б (1.07 %), RAM 1 728 Б (1.32 %).

## Репозиторій

- [x] ✅ **Немає абсолютних шляхів та згенерованих файлів.**
  - ✅ Згенерованих файлів (PDF, `.docx`, `.elf`, `.kicad_prl`, бекапи) у змінах немає.
  - ✅ `.vscode/settings.json`: абсолютний шлях замінено на
    `"${workspaceFolder}/motor-drive-controller/firmware"`.

## Підсумок

| Розділ | ✅ | ⚠️ | ❌ |
|---|:--:|:--:|:--:|
| Звіт | 2 | – | – |
| Схема | 1 | 1 | 2 |
| Прошивка | 2 | – | – |
| Репозиторій | 1 | – | – |
| **Разом (9)** | **6** | **1** | **2** |

Вимоги самого завдання 8 (імпорт DRV8305, схема підключення, сигнали ШІМ,
PWRGD/nFAULT з підтяжками, локальні мітки, датчики Холла на FT-пінах)
виконані. Невиконані пункти чекліста — це вимоги до готовності схеми до
розведення плати. Їх заплановано в `design-notes.md`.

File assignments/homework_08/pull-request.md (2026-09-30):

## Завдання

Імпортувати компонент DRV8305, створити схему його підключення за даташитом, позначити
сигнали PWM/діагностики та підключити датчики Холла до FT-пінів MCU.

**Звіт по 8 домашньому завданню:** [`assignments/homework_08/README.md`](../blob/hw08/assignments/homework_08/README.md).

## Що зроблено

**1. Вибір і імпорт компонента.** З родини DRV8305 обрано **DRV83053PHP**: промислова
версія (без суфікса Q/Q1), вбудований стабілізатор на 3.3 В — під наявне живлення MCU,
корпус HTQFP-48 (PHP) у лотках, зручний для ручної пайки. Повний розбір суфіксів —
у звіті. Компонент із SnapEDA покладено в репозиторій як самодостатню бібліотеку:

```
motor-drive-controller/hardware/kicad/lib/parts/DRV83053PHP/
├── DRV83053PHP.kicad_sym
├── DRV83053PHP.step
└── DRV83053PHP.pretty/
    └── QFP50P900X900X120-49N.kicad_mod
```

Бібліотеки підключені як *Project Specific* через `${KIPRJMOD}`, datasheet додано в
`datasheets.txt` — проєкт відкривається на будь-якому комп'ютері без налаштувань.

**2. Схема драйвера** — новий лист [`gate-driver.kicad_sch`](../blob/hw08/motor-drive-controller/hardware/kicad/gate-driver.kicad_sch):
DRV83053PHP, 8 конденсаторів і 3 резистори за таблицею *External Components* (ст. 5
даташиту). Живлення логіки — +3V3, на VDRAIN подано напругу двигуна +12M.

**3. PWM.** Виходи advanced-таймера TIM1 позначено мітками `INHA…INLC` на обох листах —
і на схемі MCU, і на схемі драйвера. Ті самі імена задано як *User Label* у CubeMX,
тож вони однакові на схемі, в `.ioc` і в коді (`INHA_Pin`…`INLC_Pin`):

| Сигнал | Пін MCU | Функція | Вивід DRV8305 |
|---|---|---|---|
| INHA / INLA | PA8 / PA7 | TIM1_CH1 / CH1N | 2 / 3 |
| INHB / INLB | PA9 / PB0 | TIM1_CH2 / CH2N | 4 / 5 |
| INHC / INLC | PA10 / PB1 | TIM1_CH3 / CH3N | 6 / 7 |

**4. Діагностика.** Сигнали `DRV_nFAULT` і `DRV_PWRGD` виведено на схему з
підтягувальними резисторами 10 кОм (open-drain, номінал за таблицею *Pin Functions*).
У CubeMX налаштовані як входи: PC4 — nFAULT, PC5 — PWRGD.

**5. Мітки.** Усім нетам на обох листах присвоєно локальні мітки: живлення (PVDD, DVDD,
AVDD, VREG, VCPH), затвори (GHA…GLC), фази (PHASE_A…C) та входи підсилювачів струму
(SN_HA…SN_LC, SLA…SLC).

**6. Датчики Холла.** `HALL1…HALL3` підключено до **PC6, PC7, PC8** — пінів з
підтримкою 5 V tolerant I/O (FT) за даташитом STM32F405 (DM00037051, с. 48–61).
У CubeMX налаштовані як GPIO-входи.

Конфігурацію MCU оновлено в [`motor-drive-controller.ioc`](../blob/hw08/motor-drive-controller/firmware/motor-drive-controller.ioc),
код перегенеровано: визначення пінів у `Core/Inc/main.h`, входи GPIOC — у `MX_GPIO_Init`,
піни ШІМ — у `HAL_TIM_MspPostInit`. Тактування виправлено: HSE 8 МГц → PLL → 168 МГц.
Прошивка збирається без попереджень (FLASH 1.07 %, RAM 1.32 %).

## Де дивитися

- **Звіт із розбором вибору компонента:** [`assignments/homework_08/README.md`](../blob/hw08/assignments/homework_08/README.md)
- **Схема драйвера:** [`gate-driver.kicad_sch`](../blob/hw08/motor-drive-controller/hardware/kicad/gate-driver.kicad_sch)
- **Схема MCU:** [`mcu.kicad_sch`](../blob/hw08/motor-drive-controller/hardware/kicad/mcu.kicad_sch)
- **Скріншоти** (схема драйвера, схема MCU, Pinout View, FT-піни) — у звіті.
- **Інженерні рішення та відкриті питання:** [`design-notes.md`](../blob/hw08/motor-drive-controller/docs/design-notes.md)
- **Перевірка за чеклістом:** [`checklist.md`](../blob/hw08/assignments/homework_08/checklist.md)
- **Схема у PDF, BOM, звіт ERC, звіт `.docx`:** вкладка **Checks → CI → Artifacts**.

Локально: `make hardware` (ERC + PDF + BOM), `make report HW=08` (звіт у `.docx`),
`make firmware` (збірка прошивки).

## Стан ERC і відкриті питання

`make hardware` дає 123 порушення (73 error, 50 warning). Вимоги завдання виконані;
порушення стосуються готовності схеми до розведення плати:

- **Міжлистові з'єднання.** Сигнали між листами MCU, Gate Driver та Inverter позначені
  *локальними* мітками, як вимагало завдання, тому електрично вони поки не з'єднані —
  звідси 45 попереджень `isolated_pin_label` і 23 `pin_not_driven`. Для реального
  з'єднання потрібні ієрархічні мітки з пінами листа або глобальні мітки.
- **41 непідключений пін** MCU і драйвера — будуть задіяні в наступних завданнях
  (SPI-керування драйвером, виходи підсилювачів струму SO1–SO3 → ADC).
- **Footprint'и пасивних компонентів** ще не призначені (є у 14 з 54 компонентів).

Знайдені під час аналізу схеми питання, які треба закрити до розведення плати
(детально — у [`design-notes.md`](../blob/hw08/motor-drive-controller/docs/design-notes.md)):

- шина +3.3V MCU живиться лише від VREG драйвера — перевірити запас струму та
  поведінку VREG у режимі sleep / при аварії;
- WAKE і EN_GATE драйвера не підключені;
- термопад драйвера (EP) не з'єднаний з GND;
- nFAULT варто завести на TIM1_BKIN (вільний PA6) для апаратного вимкнення ШІМ;
- dead-time TIM1 = 0, Break вимкнено;
- датчики Холла живляться від +5V, джерела якого на схемі ще немає.

## Чекліст

Детальна перевірка кожного пункту — у [`checklist.md`](../blob/hw08/assignments/homework_08/checklist.md).

**Звіт**
- [x] Звіт у Markdown оновлено, зображення в `images/`
- [x] Рішення та відкриті питання внесені в `design-notes.md`

**Схема (KiCad)**
- [x] Новий компонент у `lib/parts/DRV83053PHP/`, бібліотеки через `${KIPRJMOD}`,
      datasheet у `datasheets.txt`
- [ ] Усі компоненти мають номінал і footprint — номінали є, footprint'и пасивних
      компонентів ще не призначені
- [ ] Сигнали між листами з'єднані ієрархічними/глобальними мітками — за завданням
      використано локальні
- [ ] ERC: порушення пояснені, виправлення — у наступних завданнях

**Прошивка (CubeMX)**
- [x] Імена пінів у `.ioc` збігаються з мітками на схемі
- [x] Код перегенеровано, прошивка збирається (`make firmware`)

**Репозиторій**
- [x] Немає абсолютних шляхів та згенерованих файлів

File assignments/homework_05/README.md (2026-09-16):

# Заняття 5: Цифрова схемотехніка. Симуляції схем.

### Завдання 1 — частота дискретизації АЦП

Датчик у нормальному стані формує напругу 0 В. При виникненні події він формує прямокутний імпульс напругою 3 В тривалістю 2 мс. Такий імпульс виникає приблизно один раз на секунду, але момент його появи наперед невідомий. Мікроконтролер безперервно зчитує сигнал за допомогою АЦП.

Розрахуйте частоту дискретизації, щоб АЦП гарантовано виконав 5 вимірювань протягом імпульсу.

Рішення: Ось графік, на якому зображено імпульс датчику Vout_s, довжиною в Tsensor = 2 мс і додатковий графік у вигляді імпульсів, що показує частоту зчитування сигналу за допомогою АЦП (кожен імпульс — це одне зчитування). На даному графіку зчитування починається разом з початком імпульсу датчика:

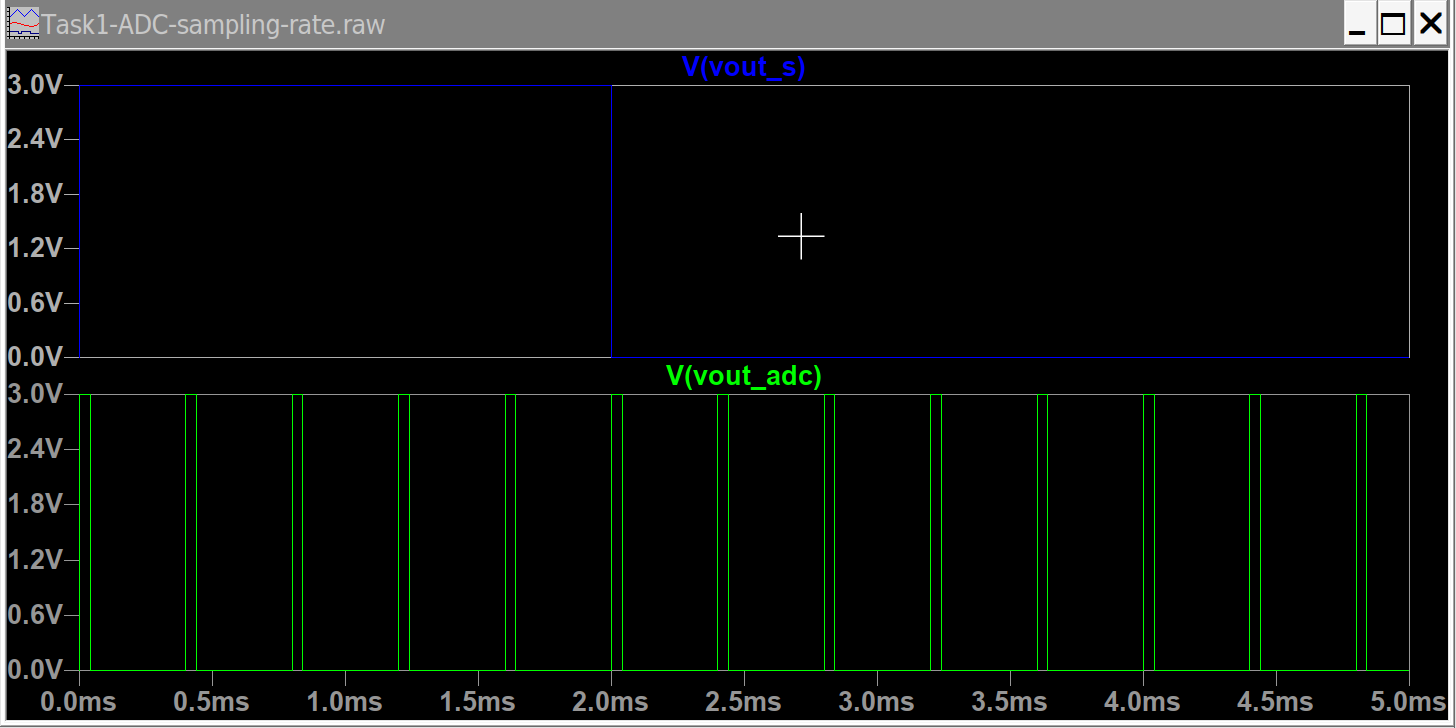
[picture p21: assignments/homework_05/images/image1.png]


При даних умовах ми гарантовано повинні зчитати гарантовано 5 вимірювань (починаючи з початку імпульсу сигналу). В даному випадку в імпульс попадають 5 проміжків між подіями зчитування сигналу і можемо читати 5 разів якщо перше зчитування починається з початком самого імпульсу.

Якщо ж сигнал зміщується, то мінімальна кількість подій зчитування дорівнює 5:

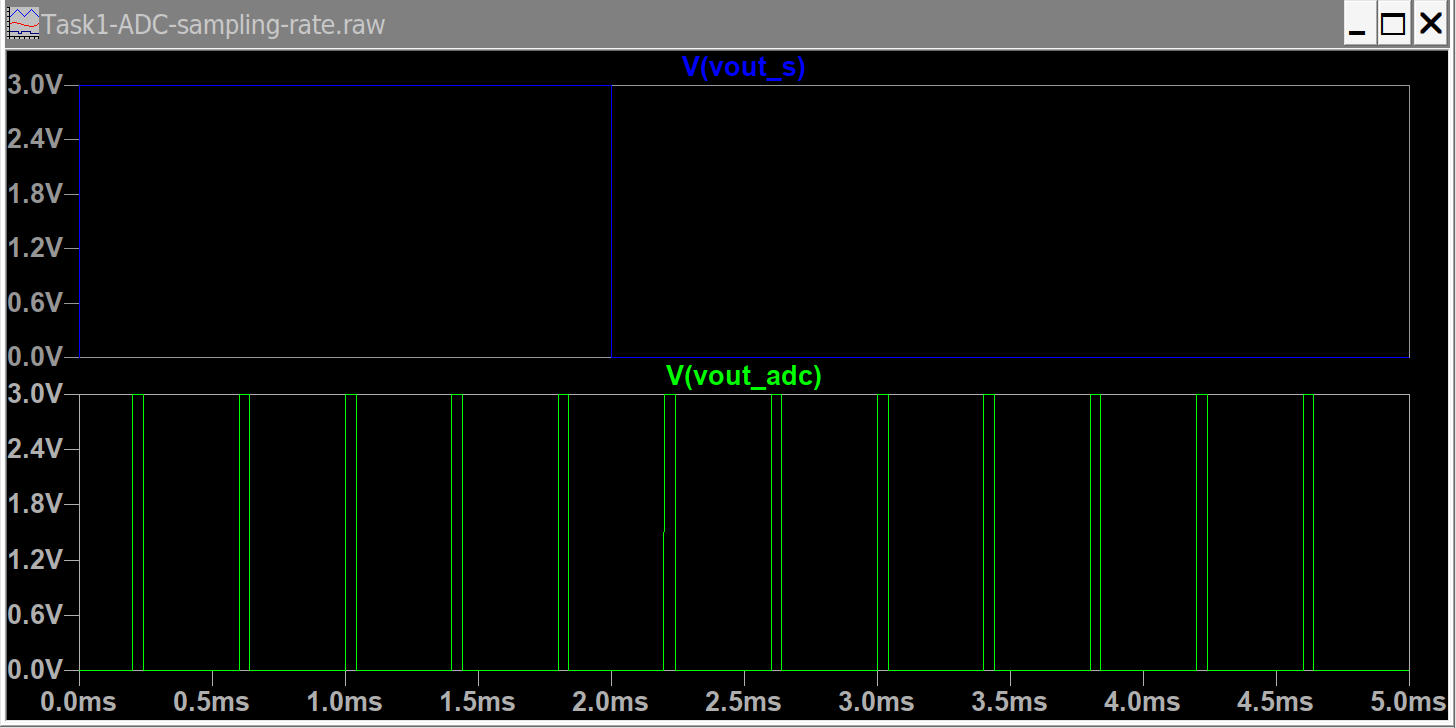
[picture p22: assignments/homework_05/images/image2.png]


Останній момент, коли може відбутися зчитування це коли процес зчитування завершується саме тоді, коли завершується імпульс датчика:

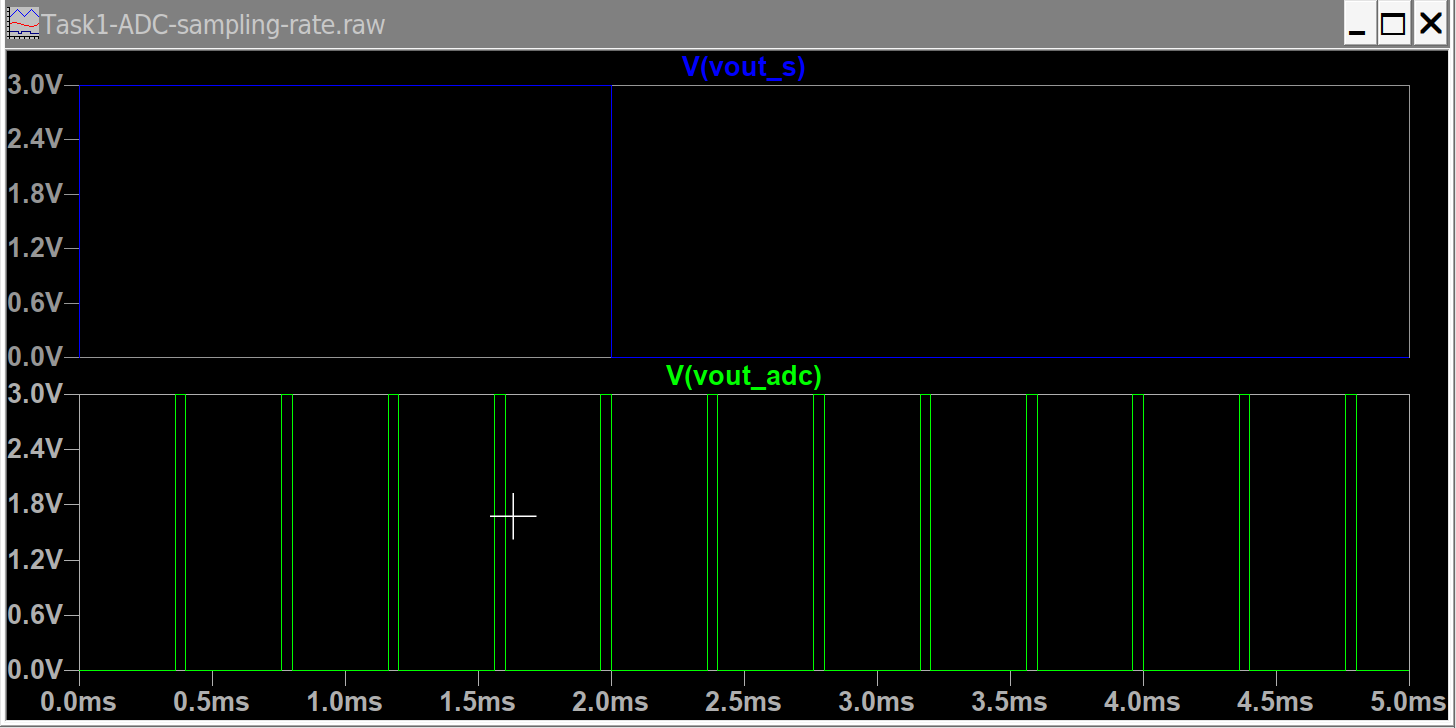
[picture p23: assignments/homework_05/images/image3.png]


Відповідно для того, щоб умови задачі виконувалися потрібно так підібрати частоту, щоб кількість періодів зчитування була \> 5.

**Узагальнений розрахунок** (якщо не враховувати час, необхідний для перетворення аналогового сигнала в цифровий):

Розраховуємо період зчитування: Tadc_read \<= Tsensor / 5 = 2 ms / 5 = 0.4 ms.

Частота зчитування Fread відповідно буде \>= 1 / Tadc_read = 1 / 0.4 ms = 1 / 0.0004 = 2500 Гц.

**Узагальнена відповідь:**

Для гарантованого отримання щонайменше 5 вимірювань під час імпульсу тривалістю 2 мс період дискретизації повинен бути не більшим за 0.4 мс. Відповідно, частота дискретизації АЦП повинна \>= 2.5 кГц. На практиці доцільно вибрати частоту дещо вищу за 2.5 кГц, наприклад 3 кГц або більше.

**Точний розрахунок** (якщо враховувати час, необхідний для перетворення аналогового сигналу в цифровий):

Час, необхідний для перетворення Tconvert.

Тоді період зчитування: Tadc_read \<= (Tsensor — Tconvert) / 5.

Частота зчитування Fread відповідно буде \>= 1 / Tadc_read.

Порівняльна таблиця характеристик АЦП:

| АЦП / Платформа | Мінімальний час одного вимірювання | Максимальна швидкість (SPS) | Розрядність (по бітах) | Особливості швидкісного режиму |
|----|----|----|----|----|
| **STM32** (вбудований) | **від 0,18 до 1 мкс** | 1 000 000 – 5 330 000 SPS | 12 біт (типово) | Потрібно використовувати **DMA** та тактування від таймера. |
| **ESP32** (вбудований) | **від 5 до 10 мкс** | до 100 000 – 200 000 SPS | 12 біт | Надвисока швидкість (до 2 MSPS теорія) доступна тільки через **I2S/DMA при вимкненому Wi-Fi**. |
| **ADS1115** (зовнішній) | **1,16 мс** (1160 мкс) | до 860 SPS | **16 біт** | Обмежений швидкістю шини **I2C** та архітектурою Delta-Sigma. |

Де SPS - Samples Per Second - Вибірок за секунду.

**Точна відповідь для STM32:**

Час, необхідний для перетворення Tconvert = 1 мкс.

Тоді період зчитування: Tadc_read \<= (Tsensor — Tconvert) / 5 = (2 мс — 1 мкс) / 5 = (0.002 - 0.000001) / 5 = 0.0003998 с.

Частота зчитування відповідно буде \>= 1 / Tadc_read = 1 / 0.0003998 с ≈ 2501.25 Гц.

Приводимо частоту до найближчої більшої, отримуємо **Fread \>= 2502 Гц**.

**Точна відповідь для ESP32:**

Час, необхідний для перетворення Tconvert = 10 мкс.

Тоді період зчитування: Tadc_read \<= (Tsensor — Tconvert) / 5 = (2 мс — 10 мкс) / 5 = (0.002 - 0.00001) / 5 = 0.000398 с.

Частота зчитування відповідно буде \>= 1 / Tadc_read = 1 / 0.000398 с ≈ 2512.56 Гц.

Приводимо частоту до найближчої більшої, отримуємо **Fread \>= 2513 Гц**.

**Точна відповідь для ADS1115:**

Час, необхідний для перетворення Tconvert = 1.16 мкс.

Тоді період зчитування: Tadc_read \<= (Tsensor — Tconvert) / 5 = (2 мс — 1.16 мкс) / 5 = (0.002 - 0.00000116) / 5 = 0.000399768 с.

Частота зчитування відповідно буде \>= 1 / Tadc_read = 1 / 0.000399768 с ≈ 2501.45 Гц.

Приводимо частоту до найближчої більшої, отримуємо **Fread \>= 2502 Гц**.

### Завдання 2 — код ЦАП (DAC)

Є 8-бітний цифро-аналоговий перетворювач (DAC). Максимальна вихідна напруга DAC становить 3,0 В. Необхідно сформувати на виході напругу 1,3 В.

Розрахуйте цифровий код, який потрібно записати в регістр DAC, та фактичну напругу на виході.

8 біт — це байт, тобто 256 значень. Але значення 0 не приймає участь у формуванні вихідної напруги, тому реальних значень буде 255. В цьому випадку якщо в регістр записуємо значення 0 (0x00), то отримуємо 0.0 В. Якщо записуємо число 255 (0xFF), то отримуємо максимальну вихідну напругу 3.0 В.

Ділимо максимальну вихідну напругу на 255, отримуємо Vdiscr = 0.011764706 В на один крок дискретизації.

Я перевірив для кожного значення регістру і розрахував вихідну напругу:

| Register value | Vout, V |
|---|---|
| 0 | 0.00000000  |
| 1 | 0.01176471  |
| 2 | 0.02352941  |
| 3 | 0.03529412  |
| … | … |
| 253 | 2.97647062  |
| 254 | 2.98823532  |
| 255 | 3.00000003  |

Для того, щоб розрахувати значення яке потрібно записати в регістр, потрібно його поділити на значення кроку дискредитації: Rnum1.3 = 1.3 В / Vdiscr = 1.3 В / 0.011764706 В = 110.499998895. Так як це має бути ціле число, то ми повинні округлити його до найближчого цілого.

Vout110 = 110 \* 0.011764706 В = 1.29411766 В.

Отримуємо різницю по модулю Vdelta110 = \|1.3 В - 1.29411766 В\| = 0.00588234 В.

Vout111 = 111 \* 0.011764706 В = 1.305882366 В.

Отримуємо різницю по модулю Vdelta111 = \|1.3 В - 1.305882366 В\| = 0.005882366 В.

Дивимося на найближчі значення:

| Register value | Vout, V | Vdelta  |
|---|---|---|
| 110 | 1.29411766  | 0.005882340 |
| 111 | 1.30588237  | 0.005882366 |

В даному випадку більш точне значення напруги 1.3 В відповідає значенню регістра 110.

Відповідь: Для того щоб на виході з 8-бітного цифро-аналогового перетворювача (DAC) сформувати на виході напругу 1,3 В потрібно в регістр перетворювача записати значення 110 (0x6E).

Фактична напруга буде в цьому випадку дорівнювати 1.29411766 В.

### Завдання 3 — побудова NOR елемента

Побудуйте NOR елемент, використовуючи базові логічні елементи (схему для побудови знайдете в презентації лекції).

Побудова схеми:

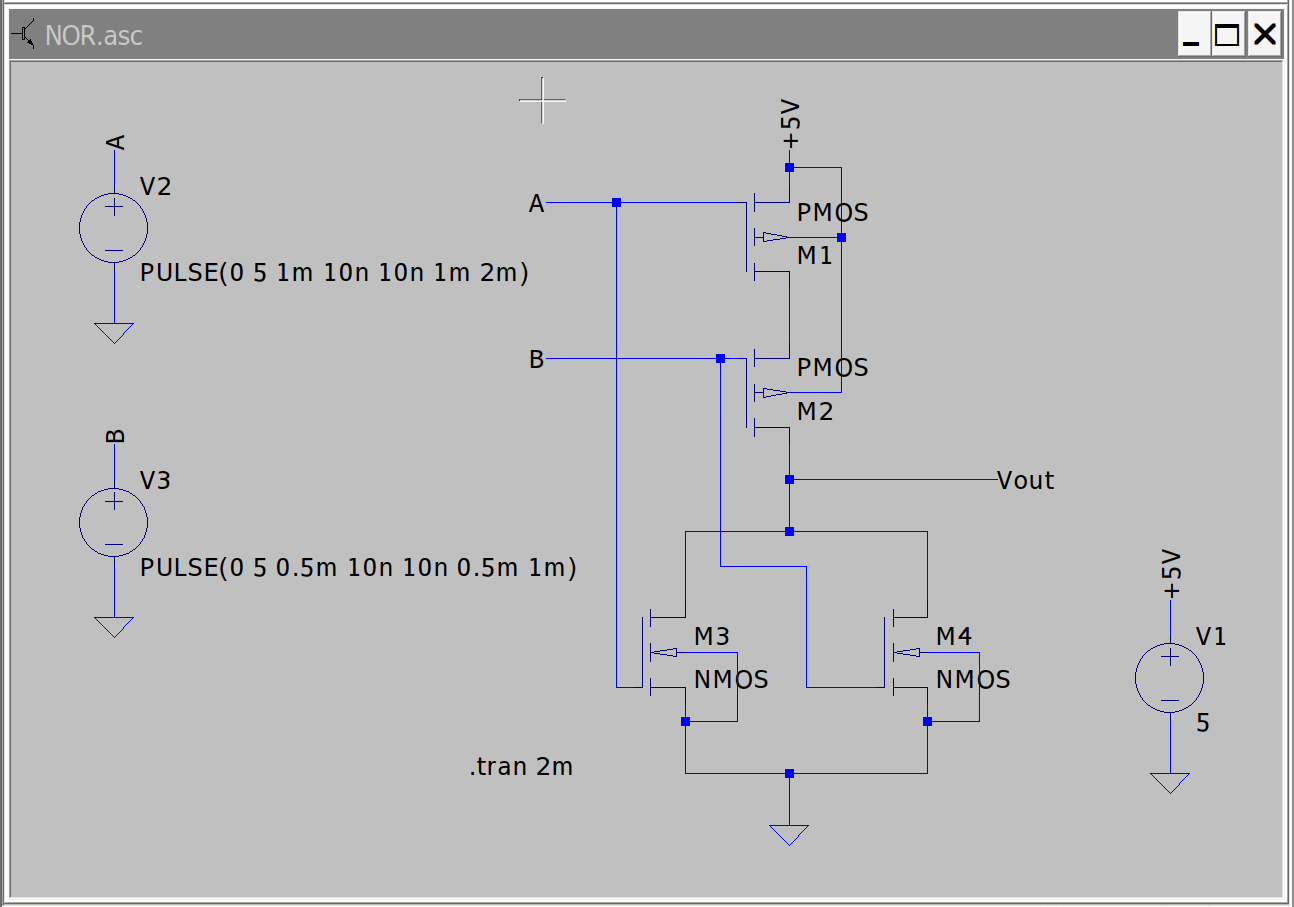
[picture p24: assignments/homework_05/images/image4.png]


Запуск симуляції:



Як видно на графіку всі логічні сигнали в певний час відповідають логіці оператора NOR:

| | | | |
|:---:|:-----:|:-----:|:---:|
| **Time** | **A** | **B** | **Vout** |
|  0.2 c | 0 | 0 | 1 |
|  0.8 c | 0 | 1 | 0 |
|  1.2 c | 1 | 0 | 0 |
|  1.8 c | 1 | 1 | 0 |

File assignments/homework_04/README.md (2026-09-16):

# Заняття 4: Аналогова схемотехніка. Симуляції схем.

### Завдання 1 — пасивний фільтр низьких частот

Дано: C = 47 нФ, R = 1 кОм



Розрахуйте частоту зрізу (cut-off frequency) fc.

Схема пасивного фільтра низьких частот:



1)  Частота зрізу:

- Формула для розрахунку:
  Частота зрізу — це частота, на якій реактивний опір конденсатора (Xc = 1/(2\*Pi\*F\*C)) стає рівним опору резистора R.
  Тобто Xc = 1/(2\*Pi\*F\*C) = R --\> Fc = 1 / (2\*Pi\*R\*C)

- Розрахунок частоти зрізу:
  Fc = 1 / (2\*Pi\*R\*C) = 1÷(2×π×1000×0.000000047) ≈ 3386.28 Гц ≈ 3.39 кГц

Чомусь не вдалось автоматично відобразити на графіку частоту зрізу (можливо стара версія додатку), тому зробив це вручну — приблизно виставив значення (дві білі переривчаті прямі — горизонтальна та вертикальна):



Це означає: На цій частоті амплітуда вихідного сигналу зменшиться на 3дБ (становить близько 70% від вхідної напруги).

На графіку також видно фазовий зсув у часі. В точці частоти зрізу настає баланс сил — активний опір резистора (R) дорівнює реактивному опору конденсатора (Xc = 1кОм). Оскільки вони ділять напругу порівну, схема є наполовину активною (резистивною) та наполовину реактивною (ємнісною). Але резистор дає зсув фази 0 градусів, конденсатор -90 градусів, то середнє значення в цій точці ми отримуємо -45 градусів.

Другий варіант розрахунку — зсув фази розраховується як арктангенс відношення опорів:
Fi = -arctan(R / Xc). Оскільки на частоті зрізу R = Xc, то:
Fi = -arctan(1) = -45 градусів.

### Завдання 2 — тип та параметри підсилювача

Дано: R2 = 12 кОм, Ku = 37



Розрахуйте параметри підсилювача, визначте його тип.

- Розрахунок параметрів підсилювача:

Коефіцієнт підсилення Ku = 1 + R2 / R1 = 37

Отримуємо формулу: 1 + R2 / R1 = 37 --\> R2 / R1 = 37 - 1 --\> R2 = 36 \* R1 --\>

R1 = R2 / 36 = 12k / 36 = 1k/3 = 333 Ом ≈ 330 Ом

Перевірка: Ku = 1 + R2 / R1 = 1 + 12000 / 330 ≈ 37.36 ≈ 37

- Визначення типу підсилювача:

  Змоделював 3 типи підсилювачів — неінвертуючий, інвертуючий та повторювач напруги (буфер):



З усіх типів самий схожий на наш - U1: **неінвертуючий** підсилювач (хоча перший раз я подумав що це був інвертуючий ☺).

  Отримав наступні графіки:



Де vin - вхідна напруга = 0.5 вольт на самому початку,

out_noninv - вихід неінвертуючого підсилювача = 1.5 вольта (Ku =1 + 2/1 = 3)

out_inv - вихід інвертуючого підсилювача = -1.0 вольт (Ku =- 2/1 = -2)

out_buff - вихід повторювача напруги (буфера) = 0.5 вольт (Ku = 1)

### Завдання 3 — замір струму колекторного двигуна

Є схема заміру струму колекторного двигуна. Підсилювач AD823A. Очікуваний максимальний струм двигуна — 2.5 А.



Порахуйте очікуваний сигнал на виході схеми. Перевірте розрахунок, просимулювавши схему в LTspice.

1\. Розраховуємо напругу на шунті між точками Vin- та Vin+:

Vshunt = I \* Rshunt = 2.5 \* 0.062 = 155 мВ

2\. Розраховуємо коефіцієнт підсилення Ku:

Ku = R2 / R1 = 15k / 1k = 15

3\. Очікувана напруга на виході Vout:

Vout = Vshunt \* Ku = 0.155 В \* 15 = 2.325 В

4\. Перевірка операційного підсилювача:

Якщо подивитися на [datasheet](https://www.analog.com/media/en/technical-documentation/data-sheets/AD823A.pdf) то в характеристиках при +5 вольтах живлення визначені такі характеристики:

- вхідний діапазон (Input Common-Mode Voltage Range), V: −0.2 to +3.8

- вихідна напруга (Output Voltage Swing), V: 0.009 to 4.98

Що повністю задовільняє нашим вимогам:

- максимальна вхідна напруга Vshunt = 155 мВ лежить в {−0.2 to +3.8}

- максимальна вихідна напруга Vout = 2.325 В лежить в {0.009 to 4.98}

5\. Симуляція в LTspice:

Поставив замість джерела живлення та двигуна джерело струму на 2.5 А

Всі наші розрахунки вірні:

- максимальна вхідна напруга Vshunt = 0.154999 В ≈ 155 мВ

- максимальна вихідна напруга Vout = 2.32497 В ≈ 2.325 В



6\. Графік вихідної напруги в залежності від струму в двигуні.



7\. Графік вхідної та вихідної напруги в часі.



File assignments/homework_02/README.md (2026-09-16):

# Заняття 2: Основні поняття в електроніці.

### Завдання

1\. Подаючи прямокутний сигнал, просимулюйте роботу **RC-ланцюга**, змінюючи параметри компонентів (збільшіть R×2, зменшіть R, зменшіть C).

2\. Подаючи прямокутний сигнал, просимулюйте роботу **RL-ланцюга**, змінюючи параметри компонентів.

3\. Знайдіть Datasheet будь-якого **MOSFET** і випишіть: максимальну напругу, максимальний струм, корпус.

1)  RC-ланцюг, джерело сигналу – тривалість 1мс, період 10мс:

    1)  Зміна опору резистора:

- з параметрами R1 0.5k, C1 1u



Результат – пікі сигналу доходять до 4В

- з параметрами R1 1k, C1 1u



Результат – пікі сигналу доходять до 3В

- з параметрами R1 2k, C1 1u



Результат: пікі сигналу доходять до 2В

Висновок – від опору резистора залежить як швидко конденсатор буде заряджатися або розряджатися в ланцюгу. Чим більше значення, тим довше заряджається конденсатор і тим ніжчі пікі.

1)  Зміна ємності конденсатора:

- з параметрами R1 1k, C1 0.5u



Результат – пікі сигналу доходять до 4В

- з параметрами R1 1k, C1 1u



Результат – пікі сигналу доходять до 3В

- з параметрами R1 1k, C1 2u



Результат: пікі сигналу доходять до 2В

Висновок – від ємності конденсатора залежить як швидко він буде заряджатися або розряджатися в ланцюгу. Чим більше значення, тим довше заряджається конденсатор і тим ніжчі пікі.

1)  FFT перетворення для схеми з параметрами R1 1k, C1 1u. Зеленим кольором видно АЧХ вхідного сигналу, синім – вихідного (на конденсаторі):



Ось графіки FFT з параметром Windowing → Blackman-Harris (намагався зробити сигнал більш візуальним):



Висновок: RC-коло є фільтром нижніх частот – видно як після проходження через елементи падає рівень високих частот. Чим вище частота, тим менше супротив конденсатора і тим ближче до землі (GND) наближується вивід конденсатора.

2)  Основні параметри розрахунку:

    1)  Частота зрізу

Fc = 1 / (2\*Pi\*R\*C) = 1÷(2×π×1000×0.000001) = 159.154943092 Гц

Це означає: На цій частоті амплітуда вихідного сигналу зменшиться на 3дБ (становить близько 70% від вхідної напруги).

2)  Стала часу tau:

tau = R \* C = 0.001

Це означає: Це час, за який конденсатор зарядиться до 63.2% від максимальної напруги (або розрядиться до 36.8% при подачі прямокутного імпульсу.

Вважається що повний заряд/розряд триває приблизно 5 \* tau = 5 мс.

Це значення приблизне, бо цей процес триває по експоненті і повний заряд означає 99.3% заряду від максимально можливого.

2)  RL-ланцюг, джерело сигналу – тривалість 5мс, період 10мс:

    1)  Зміна опору резистора:

- з параметрами R1 50, L1 50m (50 мілігенрі)



Результат: сигнал на виході зникає за 3.5 мс після зміни з 0 до 1 і навпаки.

- з параметрами R1 100, L1 50m



Результат: сигнал на виході зникає за 2.5 мс після зміни з 0 до 1 і навпаки.

- з параметрами R1 200, L1 50m



Результат: сигнал на виході зникає за 1 мс після зміни з 0 до 1 і навпаки.

1)  Зміна індуктивності:

- з параметрами R1 100, L1 25m



Результат: сигнал на виході зникає за 1 мс після зміни з 0 до 1 і навпаки.

- з параметрами R1 100, L1 50m



Результат: сигнал на виході зникає за 2.5 мс після зміни з 0 до 1 і навпаки.

- з параметрами R1 100, L1 100m



Результат: сигнал на виході зникає за 3.5 мс після зміни з 0 до 1 і навпаки.

Висновок – від індуктивності котушки залежить як швидко він буде зменшувати сигнал на виході. Чим більше значення, тим довше падає сигнал.

3)  Пошук datasheet для MOSFET AO3401:

Знайшов на сайті https://octopart.com/datasheet/alpha-omega-semiconductor/AO3401



максимальна напруга (Drain-Source Voltage, Vds): -30 В

максимальний струм (Continious Drain Current, Id): -4А

корпус (Package): SOT23



На ньому я реалізовував ключ для вимірювання температури за допомогою ратиометрії:

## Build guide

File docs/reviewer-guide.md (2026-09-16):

# Як переглянути роботу

Нічого встановлювати не потрібно — усе видно в браузері.

## 1. Звіт з домашнього завдання

Посилання, яке надсилається на перевірку, веде на одне з:

- **Pull Request** (`…/pull/N`) — вкладка **Files changed** показує, що саме
  змінилося в межах завдання; коментарі можна залишати прямо до рядків.
  Звіт `assignments/homework_NN/README.md` відкривається кнопкою
  **⋯ → View file**.
- **Release** (`…/releases/tag/hwNN`) — зафіксований стан на момент здачі.
  Внизу, у **Assets**, лежать готові файли:
  - `homework_NN.docx` — звіт у форматі Word;
  - `motor-drive-controller-schematic.pdf` — схема;
  - `motor-drive-controller-bom.csv` — перелік компонентів;
  - `motor-drive-controller-erc.rpt` — результат електричної перевірки (ERC).

## 2. Проміжні результати (без релізу)

У Pull Request: вкладка **Checks → CI → Artifacts** (потрібен вхід у GitHub).

## 3. Завантажити все на свій комп'ютер

- Без git: на головній сторінці репозиторію **Code → Download ZIP**
  (або **Source code (zip)** у релізі — саме та версія, що здавалася).
- З git:
  ```bash
  git clone https://github.com/anhro/hardware-development.git
  cd hardware-development
  git checkout hw07        # стан на момент здачі ДЗ 7
  make setup               # за бажанням: завантажити datasheets
  ```
  Схему відкривати файлом `motor-drive-controller/hardware/kicad/motor-drive-controller.kicad_pro`
  (KiCad 10) — усі бібліотеки компонентів у репозиторії, додаткове налаштування не потрібне.

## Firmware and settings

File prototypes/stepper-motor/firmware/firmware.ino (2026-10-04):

#include <AccelStepper.h>

// Піни для драйвера A4988
const int stepPin = 12;
const int dirPin = 14;

// Піни для кнопок (замикаються на GND)
const int buttonLeftPin = 26;
const int buttonRightPin = 27;

// Створюємо об'єкт двигуна (1 = режим DRIVER)
AccelStepper stepper(1, stepPin, dirPin);

void setup() {
  // Налаштування пінів кнопок із внутрішньою підтяжкою до 3.3V
  pinMode(buttonLeftPin, INPUT_PULLUP);
  pinMode(buttonRightPin, INPUT_PULLUP);

  // Налаштування базових параметрів двигуна
  // stepper.setMaxSpeed(3000);     // Максимальна швидкість (кроків/сек)
  stepper.setMaxSpeed(1000);     // Максимальна швидкість (кроків/сек)
  // stepper.setAcceleration(1000);  // Прискорення (кроків/сек^2)
  stepper.setAcceleration(500);  // Прискорення (кроків/сек^2)

  // Ініціалізація генератора випадкових чисел за допомогою шуму на аналоговому піні
  randomSeed(analogRead(34));
}

void loop() {
  // Зчитуємо стан кнопок (LOW означає, що кнопку натиснуто)
  bool leftPressed = (digitalRead(buttonLeftPin) == LOW);
  bool rightPressed = (digitalRead(buttonRightPin) == LOW);

  // Якщо натиснута кнопка ВЛІВО і двигун завершив попередній рух
  if (leftPressed && !rightPressed && stepper.distanceToGo() == 0) {
    long randomSteps = 400; //random(100, 200);      // Випадкова кількість кроків
    float randomSpeed = 1000; //random(400, 800);    // Випадкова швидкість
    
    stepper.setMaxSpeed(randomSpeed);
    stepper.move(-randomSteps);               // Рух у негативну сторону (вліво)
  }
  
  // Якщо натиснута кнопка ВПРАВО і двигун завершив попередній рух
  else if (rightPressed && !leftPressed && stepper.distanceToGo() == 0) {
    long randomSteps = 400; //random(100, 200);      // Випадкова кількість кроків
    float randomSpeed = 1000; //random(400, 800);    // Випадкова швидкість
    
    stepper.setMaxSpeed(randomSpeed);
    stepper.move(randomSteps);                // Рух у позитивну сторону (вправо)
  }
  
  // Якщо жодна кнопка не натиснута — даємо команду плавно зупинятися
  else if (!leftPressed && !rightPressed) {
    stepper.stop(); 
  }

  // Цей метод повинен викликатися постійно, він крутить двигун
  stepper.run();
}

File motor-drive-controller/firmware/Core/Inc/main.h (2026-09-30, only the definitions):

#define INLA_Pin GPIO_PIN_7
#define INLA_GPIO_Port GPIOA
#define DRV_nFAULT_Pin GPIO_PIN_4
#define DRV_nFAULT_GPIO_Port GPIOC
#define DRV_PWRGD_Pin GPIO_PIN_5
#define DRV_PWRGD_GPIO_Port GPIOC
#define INLB_Pin GPIO_PIN_0
#define INLB_GPIO_Port GPIOB
#define INLC_Pin GPIO_PIN_1
#define INLC_GPIO_Port GPIOB
#define HALL1_Pin GPIO_PIN_6
#define HALL1_GPIO_Port GPIOC
#define HALL2_Pin GPIO_PIN_7
#define HALL2_GPIO_Port GPIOC
#define HALL3_Pin GPIO_PIN_8
#define HALL3_GPIO_Port GPIOC
#define INHA_Pin GPIO_PIN_8
#define INHA_GPIO_Port GPIOA
#define INHB_Pin GPIO_PIN_9
#define INHB_GPIO_Port GPIOA
#define INHC_Pin GPIO_PIN_10
#define INHC_GPIO_Port GPIOA

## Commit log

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2026-09-16 hw05: digital circuitry, simulations
    [Calc-DAC-Values.xlsx]
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2026-09-16 hw07: MCU architecture, CubeMX configuration
    [inverter.kicad_sch, mcu.kicad_sch, motor-drive-controller.kicad_pcb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]
2026-09-16 firmware: add HAL/CMSIS drivers required for CMake build
2026-09-17 hw08(kicad): add DRV83053PHP footprint and symbol to KiCad library
2026-09-17 hw08(gate-driver): add gate driver sheet and configure MCU
    [gate-driver.kicad_sch, inverter.kicad_sch, mcu.kicad_sch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]
2026-09-18 fix(README.md): update driver specifications and improve clarity in connection instructions
2026-09-18 fix(kicad): change capacitor value from 4.7u to 1u in gate driver schematic
    [gate-driver.kicad_sch]
2026-09-18 docs(design-notes): update open issues and solutions for DRV8305 driver
2026-09-18 chore(pull_request_template): update checklist for report, schematic, firmware, and repository requirements
2026-09-18 fix(kicad): update DRV83053PHP library path and remove unused footprint
2026-09-18 feat(motor-drive): add GPIO definitions and update configurations for INLA, INLB, INHA, INHB, and INLC
2026-09-18 feat(pool-request): add detailed report and schematic for DRV8305 integration in homework 08
2026-09-18 fix(readme): update path for DRV83053PHP library and organize footprint directory
2026-09-18 feat(readme): add DRV83053PHP library directory for DRV8305 footprint
2026-09-18 docs(readme): enhance MCU and driver details, add signal mapping for DRV8305
2026-09-30 ci: enhance project detection and export steps for KiCad and CMake projects
2026-09-30 docs(README): add section for personal prototype projects and update directory structure
2026-10-04 feat(stepper-motor): add stepper driver scheme
    [stepper-motor.kicad_pcb, stepper-motor.kicad_sch]
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2026-10-04 fix(makefile): add ARDUINO_CLI variable and improve firmware build instructions
2026-10-04 feat(motor-drive): enable SPI bus
    [gate-driver.kicad_sch, mcu.kicad_sch]
2026-10-04 feat(motor-drive): add Pull-up resistor to DRV_SDO SPI1
    [mcu.kicad_sch]
2026-10-04 feat(motor-drive): add Pull-up resistor to DRV_nSCS SPI1
    [mcu.kicad_sch]
2026-10-04 feat(hw09): create links between labels of different hierarchical sheets
    [gate-driver.kicad_sch, inverter.kicad_sch, mcu.kicad_sch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]
2026-10-04 feat(hw09): rename net labels
    [gate-driver.kicad_sch, inverter.kicad_sch, mcu.kicad_sch]
2026-10-04 feat(hw09): add SPI bus connections for MCU and DRV8305 with diagrams
2026-10-04 feat(hw09): update README with new connections and add CS bus diagrams for inverter and driver
    [inverter.kicad_sch]
2026-10-04 feat(hw09): add ISENSE ADC channels and update schematics
    [gate-driver.kicad_sch, mcu.kicad_sch, motor-drive-controller.kicad_sch]
2026-10-04 fix(hw09): rename MCU net labels to match the scheme
    [main.h, motor-drive-controller.ioc]
2026-10-04 feat(hw09): update ADC channel names and schematic references to ANALOG prefix
    [gate-driver.kicad_sch, inverter.kicad_sch, mcu.kicad_sch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]
2026-10-04 feat(hw09): configure ADC for triple injected simultaneous mode and update related settings
2026-10-04 feat(hw09): update README and schematic files with JTAG connector details and resistor additions
    [mcu.kicad_sch]
2026-10-06 feat(hw09): update ADC configuration for injected channels and GPIO mappings
2026-10-06 feat(hw09): update SPI configuration for DRV8305, including data size and clock settings
2026-10-06 fix(hw09): fix the filter circuit for the real cutoff frequency and set the PWM frequency to 20 kHz
    [inverter.kicad_sch]
2026-10-06 feat(hw09): add capacitors to the power line of three-phase switches
    [inverter.kicad_sch]
2026-10-06 feat(hw09): update TIM1 configuration to use Center Aligned mode for improved PWM control
2026-10-06 fix(hw09): fix ERC issues
    [gate-driver.kicad_sch, mcu.kicad_sch]
2026-10-06 feat(hw09): add EN_GATE control and WAKE signal handling in hardware design
    [gate-driver.kicad_sch, mcu.kicad_sch, motor-drive-controller.kicad_sch]
2026-10-07 feat(hw09): update footprint properties for components in schematic files
    [gate-driver.kicad_sch, inverter.kicad_sch, mcu.kicad_sch]
2026-10-08 feat(hw09): add WAKE control signal
    [gate-driver.kicad_sch, mcu.kicad_sch]
2026-10-08 fix(hw09): update footprint property for NetTie in gate driver schematic
    [gate-driver.kicad_sch]
2026-10-08 feat(hw09): update datasheet links for components in gate driver and MCU schematics
    [gate-driver.kicad_sch, mcu.kicad_sch]
2026-10-08 fix(hw09): update ERC status and resolve multiple warnings in design notes and schematics
    [gate-driver.kicad_sch]
2026-10-08 feat(hw09): update README with new driver details and add hierarchical diagrams
2026-10-09 feat(hw10): add README for power supply circuit and architecture diagram
2026-10-14 feat(hw10): reset annotate schematic
2026-10-14 feat(hw10): add NetTie_2 symbol and update related connections in gate-driver schematic
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2026-10-15 feat(hw10): add power LDO +5V --> +3.3V schema
2026-10-15 feat(hw10): add LDO +3.3V schematic image to README
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2026-10-25 fix(hw10): correct capacitor value from 33n to 33u in power schematic
2026-10-25 fix(hw10): add XAL6060-333MEC symbol to KiCad symbol library
2026-10-25 fix(hw10): update LDO output current specification to 0.8 A in README
2026-10-25 fix(hw10): update capacitor footprints and add voltage properties in power schematic
2026-10-25 fix(hw10): add 100nF capacitor for high-frequency filtering in power schematic
2026-10-25 fix(hw10): update pin type from power_in to passive for CB in power schematic
2026-10-25 fix(hw10): clarify LDO +3.3V current consumption and dropout voltage calculations in README
2026-10-27 feat(hw10): add MF-R700 resettable fuse component files and update library references
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2026-10-27 feat(hw10): update capacitor value to 0.1u and add voltage property for components
2026-10-27 feat(hw10): update datasheets and add missing links for components in README and KiCad files
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2026-10-27 feat(hw10): add custom SS10P4 library with symbol and footprint details in documentation
2026-10-27 fix(hw10): correct terminology in checklist for Power sheet description
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2026-10-30 feat(hw11): changed "Voltage" properties to "MaxVoltage" and add new properties: "MPN", "Manufacturer", and "Supplier"
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2026-10-30 feat(hw11): update BOM export fields to include MaxVoltage, Manufacturer, MPN, and Supplier
2026-10-30 feat(hw11): update README and design notes for BOM completion and component specifications
2026-11-01 feat(hw11): replace CR2032 by S8421-45R component in KiCad library
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2026-11-01 feat(hw11): update MPN and Supplier properties in schematic files and reorder designators in project file
2026-11-01 feat(hw11): update MPN and Supplier fields in KiCad files and reorder designators in project files
2026-11-01 feat(hw11): add MaxVoltage, Manufacturer, MPN, and Supplier fields to BOM; clarify battery component status
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2026-11-02 feat(hw11): update README, checklist, and design notes; optimize BOM and remove ceramic capacitor from LDO output
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2026-11-02 feat(hw11): update component values and descriptions with real part numbers for buttons and connectors
2026-11-02 feat(hw11): update design notes and documentation for +12M capacitor ripple current; replace Nichicon with KEMET polymer capacitors

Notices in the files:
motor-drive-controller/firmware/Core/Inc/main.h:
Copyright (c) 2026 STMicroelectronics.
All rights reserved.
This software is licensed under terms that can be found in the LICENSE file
